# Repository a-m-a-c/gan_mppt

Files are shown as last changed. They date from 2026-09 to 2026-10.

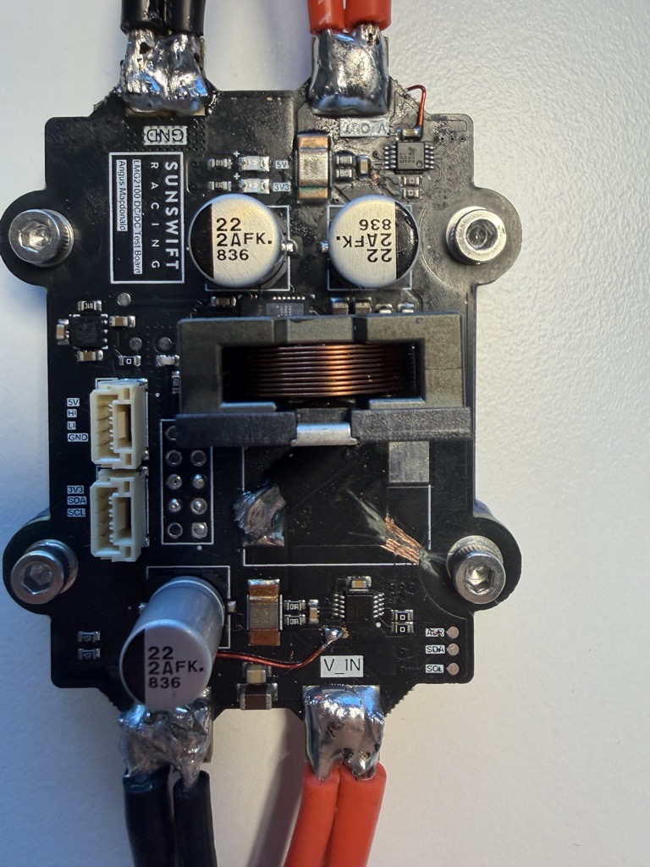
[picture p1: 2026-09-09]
docs/photos/test_board_emi_fix.jpg

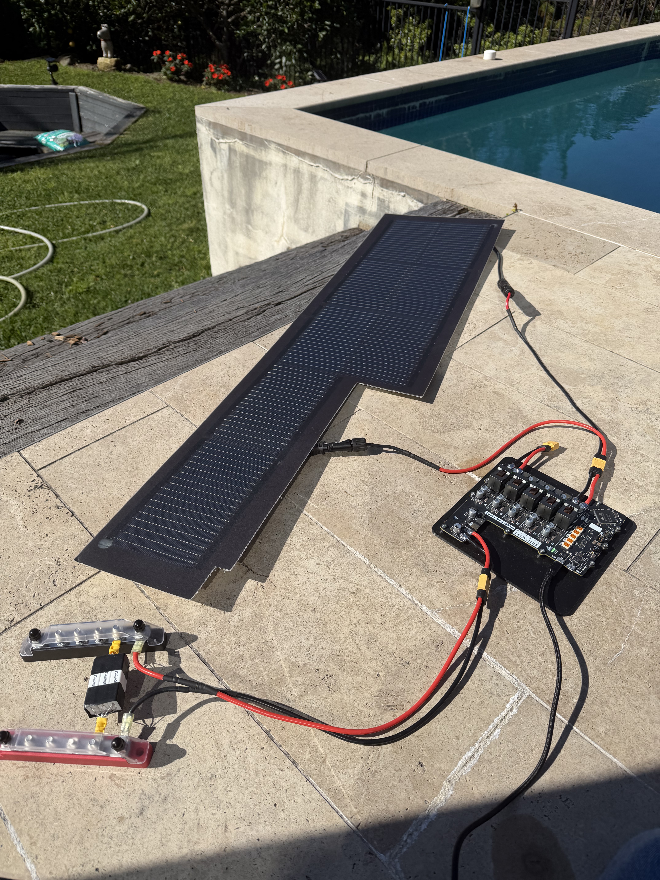
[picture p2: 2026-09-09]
docs/photos/mppt_test_with_pv.jpg

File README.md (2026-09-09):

# gan_mppt

Firmware, hardware designs, and host tools for the five-channel GaN MPPT controller.

```powershell
git clone https://github.com/a-m-a-c/gan_mppt.git
cd gan_mppt
```

| Folder | Contents |
| --- | --- |
| `firmware/` | STM32 firmware, CubeMX project, and CMake build files |
| `hardware/` | Altium schematics, PCB, output job, and schematic PDFs |
| `tools/` | Python bench GUI, serial console, capture and plotting tools; managed by uv |
| `docs/` | Project documents and plots |

Open the repository root in VS Code. Its CMake, flash, and debug settings target
`firmware/`. The firmware's CubeMX project and executable remain named
`gan_mppt_firmware`.

To compile with STM32CubeCLT's CMake, Ninja, and ARM GCC on PATH:

```powershell
cd firmware
cmake --preset Debug
cmake --build --preset Debug
```

To run the host GUI from the repository root with [uv](https://docs.astral.sh/uv/):

```powershell
uv sync --project tools --locked
uv run --project tools --locked python tools/gui/server.py
```

See [tools/README.md](tools/README.md) for the other commands. A serial connection
is selected in the GUI; opening it alone does not connect to the board.

Open `hardware/SR8_MPPT.PrjPcb` in Altium Designer. Local Altium history,
previews, logs, and generated outputs are ignored by Git.

The repository retains the original firmware Git history. Hardware was copied
from the existing Altium project without importing its Git history.

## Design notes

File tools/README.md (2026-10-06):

# GaN MPPT tools

Python 3.11 or newer and [uv](https://docs.astral.sh/uv/) are required.
Dependencies are declared in `pyproject.toml` and resolved in `uv.lock`.

Run from the repository root:

```powershell
uv sync --project tools --locked
uv run --project tools --locked python tools/gui/server.py
uv run --project tools --locked python tools/console.py --list
uv run --project tools --locked python tools/plotter.py --list
uv run --project tools --locked python tools/iv_curve.py <csv>
```

The GUI prints its local URL. Select a serial port and connect when the board
is ready. Captures are saved under the repository's ignored `captures/` folder.

Use the channel toggles above the V-I plane to overlay multiple channels.
Each channel has its own colour, trail and best-power marker. The V-I plane
and time-series plots have separate Pause buttons. Pausing freezes the view
for inspection while live values and captures continue; Resume returns to
the current live data.

To replay an existing capture without connecting to hardware:

```powershell
uv run --project tools --locked python tools/gui/server.py --replay <csv> --speed 4
```

The scripts retain their inline dependency metadata for standalone use.
Use the explicit `python` commands above to run with the project's locked
dependencies. Add shared dependencies with `uv add --project tools <package>`.

`gen_ntc_table.py` writes to `firmware/Inc/drivers/ntc_table.h` and requires
`.agents/NCU18XH103F6SRB.csv`, which is not currently included in the repository.

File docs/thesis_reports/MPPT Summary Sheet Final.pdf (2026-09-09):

Angus Macdonald - z5416730 | Supervisor - Prof. John Fletcher | Assessor - Dr. Pablo Poblete Durruty

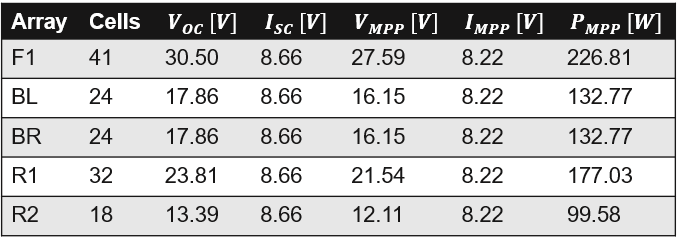
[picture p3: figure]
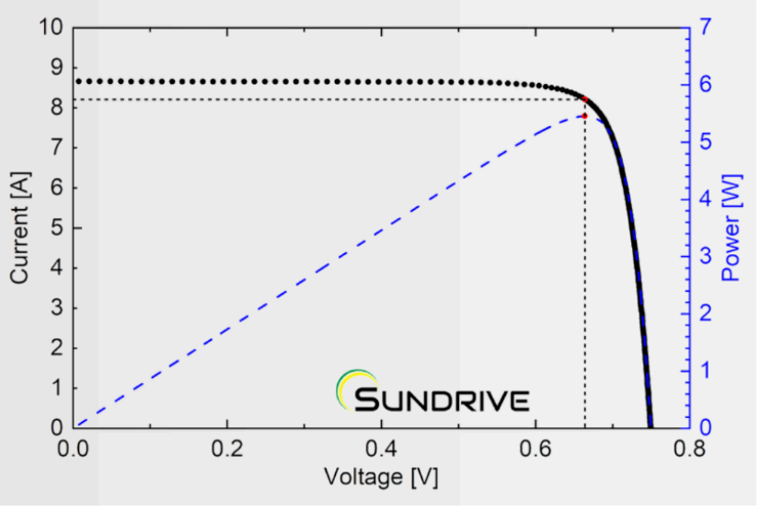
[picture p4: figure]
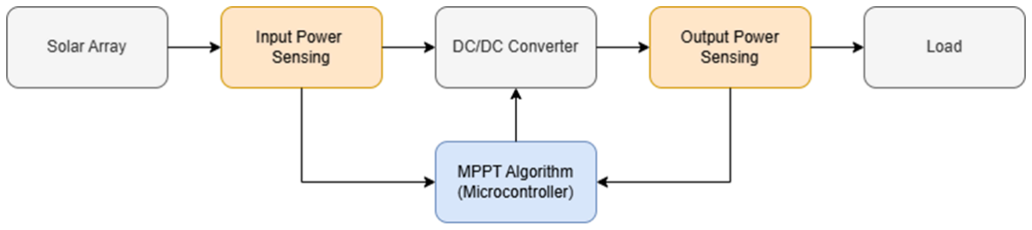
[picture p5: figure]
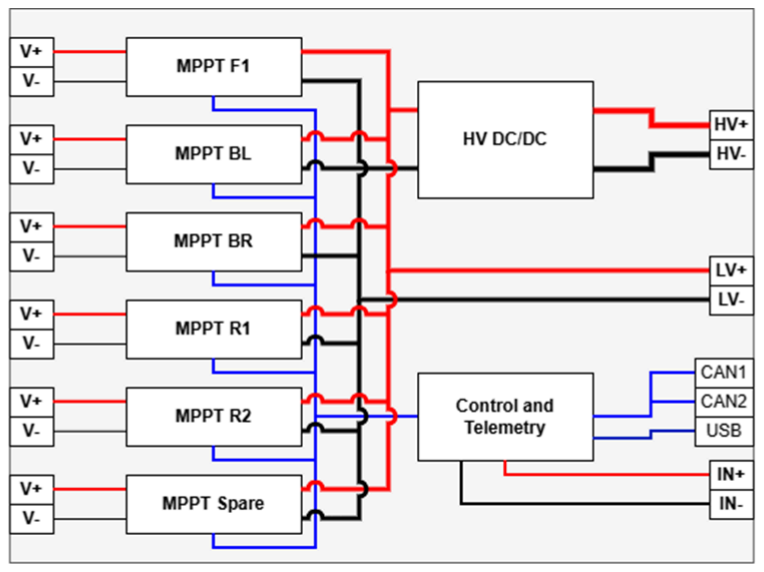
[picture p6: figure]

Maximises energy extraction under dynamic operating conditions while maintaining reliability within strict system constraints.

# Multi-Channel Solar Car MPPT

## Thesis Aim

## General Background

## Proposed System

SR8 - Sunswift 8
ADR - Australian Design Rules LV - Low Voltage
HV - High Voltage

SC - Short Circuit
OC - Open Circuit
MPPT - Maximum Power Point Tracker MPP - Maximum Power Point

PWM - Pulse Width Modulation CAN - Controller Area Network COTS - Commercial Off-The-Shelf GaN - Gallium Nitride

## SR8 System Context & Requirements

This thesis presents a multi-channel MPPT system for Sunswift 8, designed to maximise energy extraction under dynamic conditions.

The system delivers power to both LV and HV buses depending on state-ofcharge, and acts as a flexible platform for MPPT algorithm development and validation.

5 solar arrays (~769 W) feeding LV (~48V) and HV (~690V) bus. Highly dynamic operating conditions duringdriving.
Strict size, protection, & environmental constraints. Energy-limited system, efficiency is critical for range goals.

IV/PV Curve for SR8 Cells

Solar arrays exhibit non-linear I-V characteristics with a maximum power point (MPP).
MPP varies with irradiance, temperature, and partial shading. Complex control algorithms required for dynamic MPP tracking. DC/DC converters enable control of array operating point.

6 independent synchronous boost MPPT channels. Per-array tracking to minimise partial shading losses. Dual-output architecture supporting LV and HV buses. Automatic HV charging transition when LV is at capacity. STM32-based control with high-resolution PWM. Web-based UI for experimental algorithm deployment, telemetry monitoring, and array validation.
Support for FD-CAN and serial communication. Designed for high reliability and seamless integration.

# Thesis A Seminar Summary

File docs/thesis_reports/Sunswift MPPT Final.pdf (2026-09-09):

# Multi-Channel Solar Car MPPT

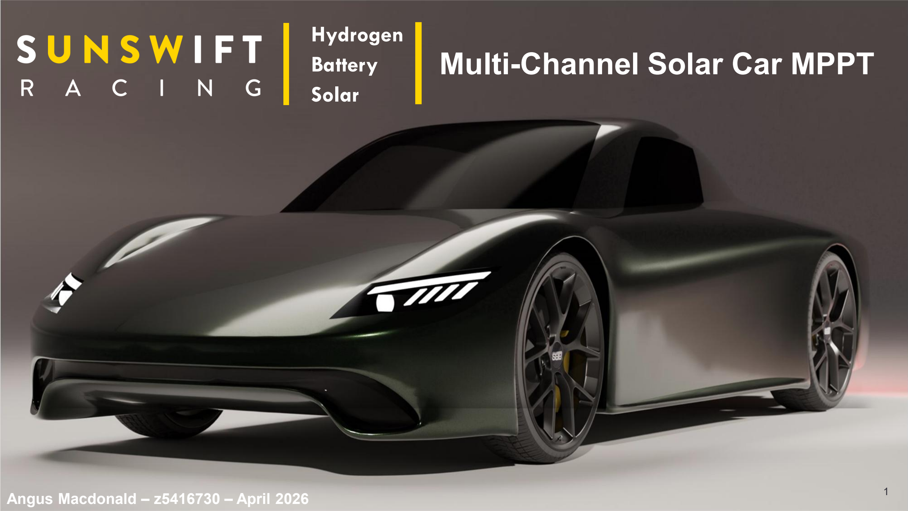
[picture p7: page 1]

### Hydrogen Battery Solar

1
Angus Macdonald – z5416730 – April 2026

# Introducing Sunswift 8

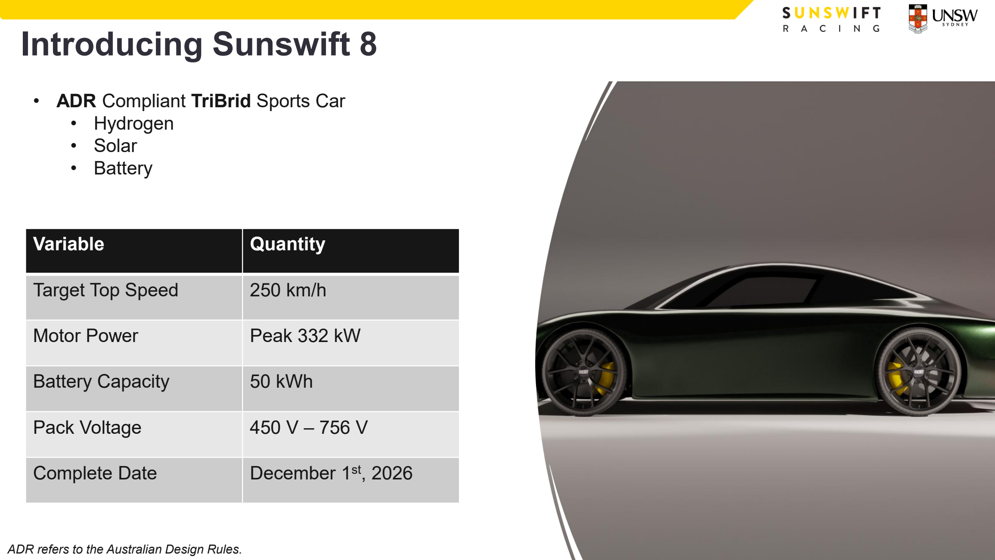
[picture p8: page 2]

2

- ADR Compliant TriBrid Sports Car
- Hydrogen
- Solar
- Battery
Variable | Quantity
Target Top Speed | 250 km/h
Motor Power | Peak 332 kW
Battery Capacity | 50 kWh
Pack Voltage | 450 V – 756 V
Complete Date | December 1st, 2026

ADR refers to the Australian Design Rules.

# Sunswift 8 Electrical Overview

3

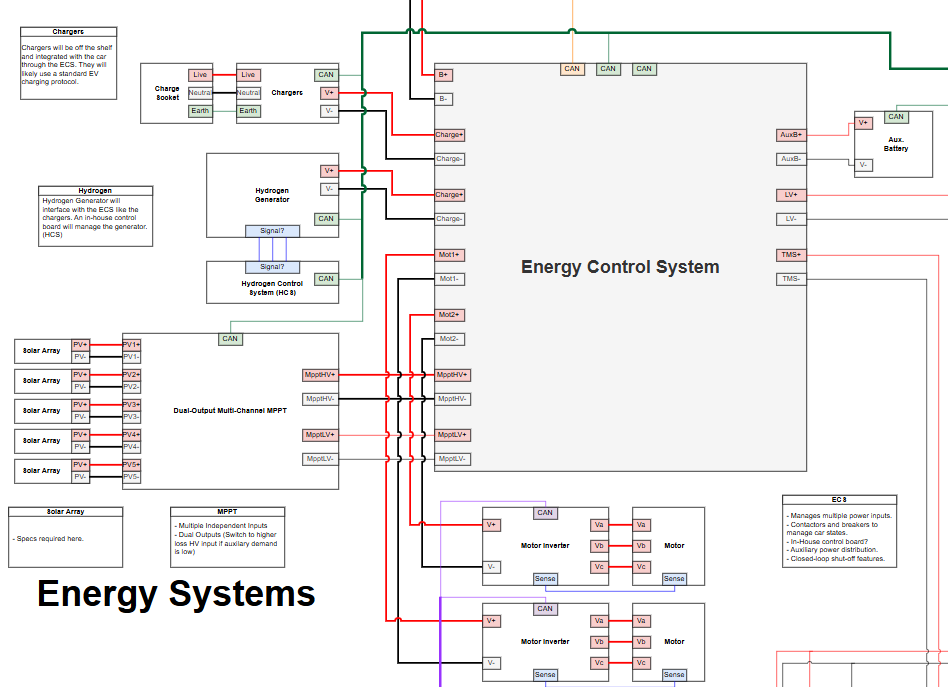
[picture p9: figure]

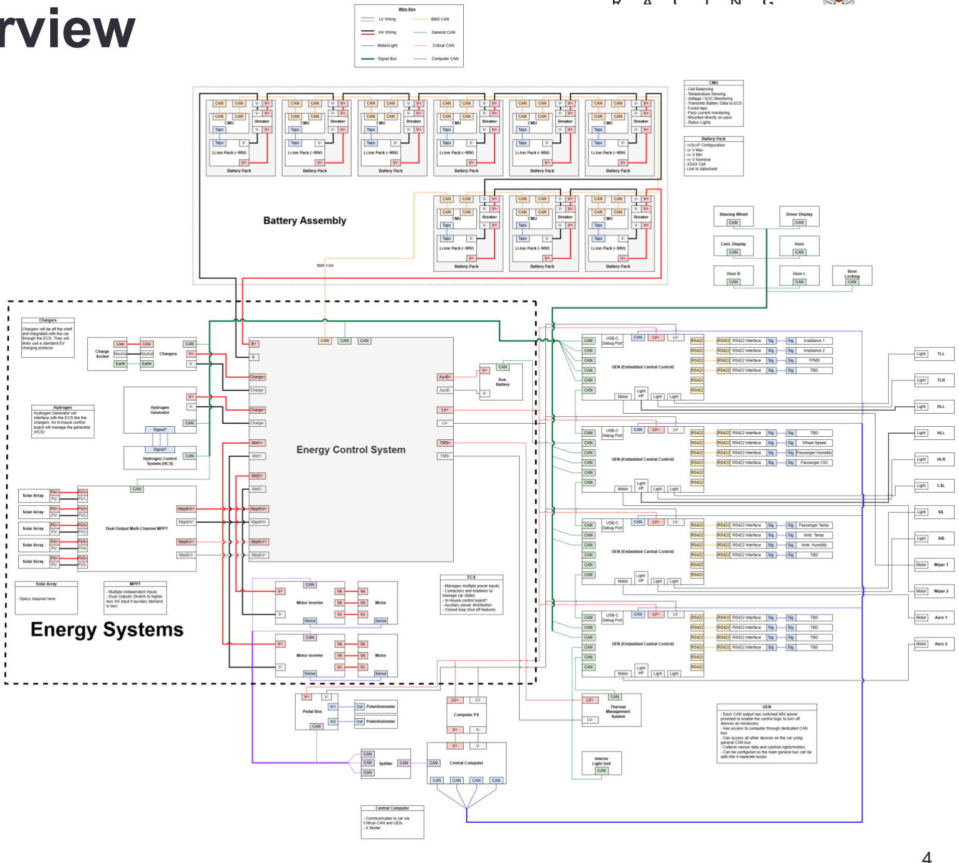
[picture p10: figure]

# Sunswift 8 Electrical Overview

4

- High

-level electrical diagram of SR8
- Battery • Energy Systems • Embedded network
- Two primary electrical bus’s • LV Bus • 13S Molicel INR-21700

-P45B
- 32.5 V minimum • 46.8 V nominal • 54.6 V maximum
- HV Bus • 180S Molicel INR -21700

-P50B
- 450 V minimum • 690 V nominal • 756 V maximum
- Two onboard power generation systems • Hydrogen Fuel Cell • Solar Array

LV indicates low voltage (<100V). HV indicates high voltage (>100V).

# Sunswift 8 Electrical Overview - Solar

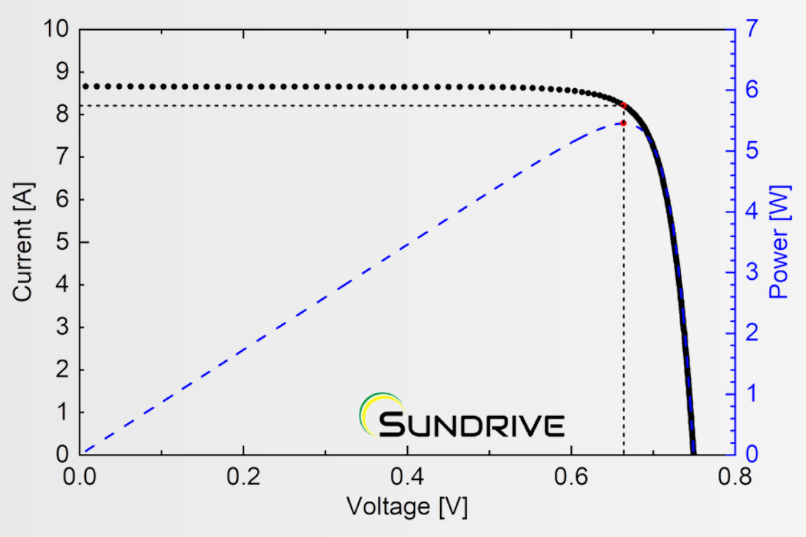
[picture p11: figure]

5

Array | Cells | VOC [V] | ISC [V] | VMPP [V] | IMPP [V] | PMPP [W]
F1 | 41 | 30.50 | 8.66 | 27.59 | 8.22 | 226.81
BL | 24 | 17.86 | 8.66 | 16.15 | 8.22 | 132.77
BR | 24 | 17.86 | 8.66 | 16.15 | 8.22 | 132.77
R1 | 32 | 23.81 | 8.66 | 21.54 | 8.22 | 177.03
R2 | 18 | 13.39 | 8.66 | 12.11 | 8.22 | 99.58

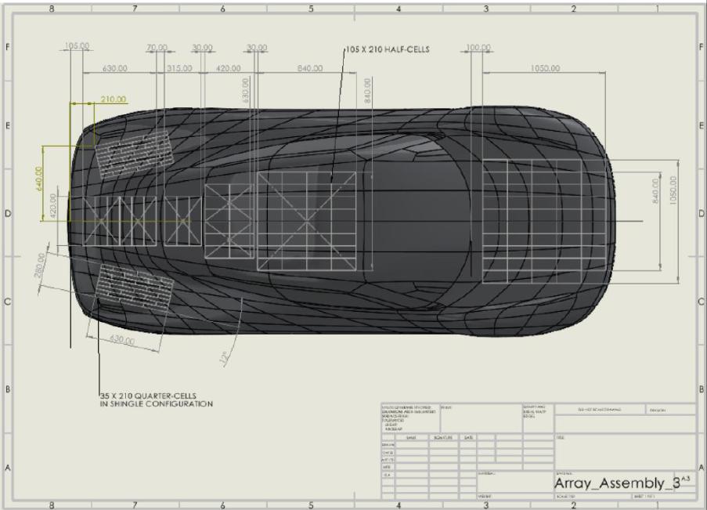
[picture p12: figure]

- SunDrive G12 – 210 SD-HJT Cells
- 25.1% efficient
- 19.35% power loss at 100 °C
- 4.13% current increase at 100 °C
- 5 arrays (all series cells)
- All on different planes.
- Different cell numbers.
- Total power of 769 W.

Values calculated at STC conditions (25 °C, 1000 W
m²

, AM1.5 Spectrum)

F, B, and R indicate front, back, and roof, respectively.

# Maximum Power Point Tracker – IV and PV Curves

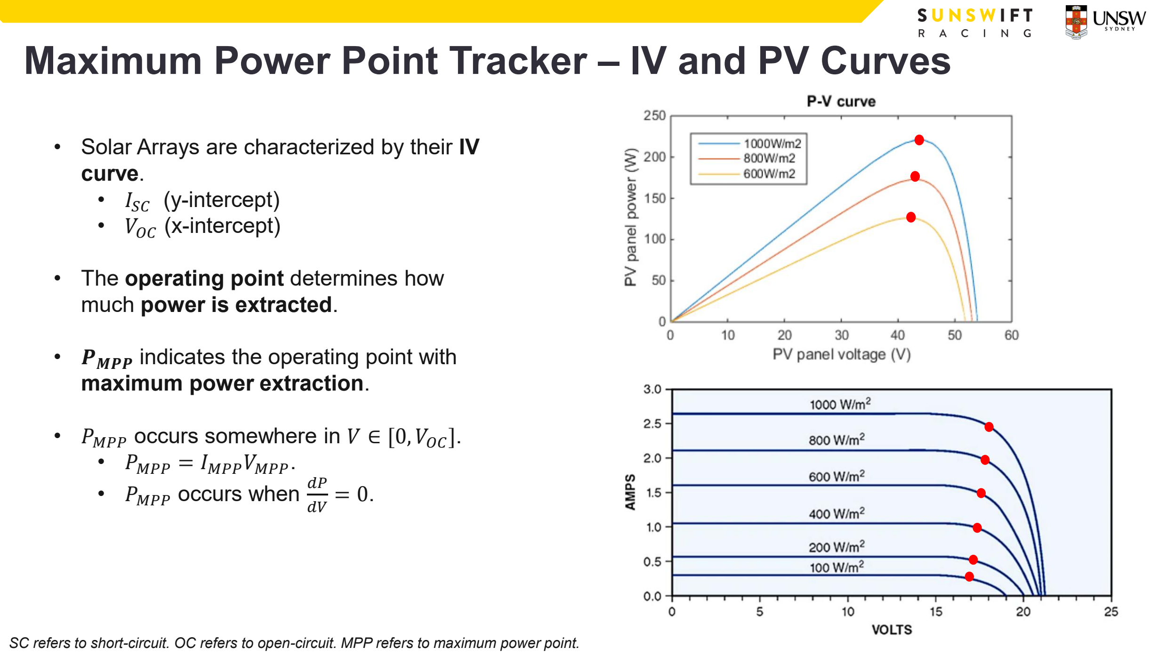
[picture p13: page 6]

- Solar Arrays are characterized by their IV curve.
- ISC (y-intercept)
- VOC (x-intercept)
- The operating point determines how much power is extracted.
- PMPP indicates the operating point with maximum power extraction.
- PMPP occurs somewhere in V ∈ [0, VOC].
- PMPP = IMPPVMPP.
- PMPP occurs when dP
dV

= 0.

SC refers to short-circuit. OC refers to open-circuit. MPP refers to maximum power point.

# Maximum Power Point Tracker – Purpose

- The goal is to operate the panel at PMPP.
- Not doing this results in underutilization of solar resources.
- To operate at PMPP, it must first be found.
- PV curves can have multiple maxima.
- PMPP is dynamic. It requires active tracking.
- Environmental variables are constantly altering the IV curve.

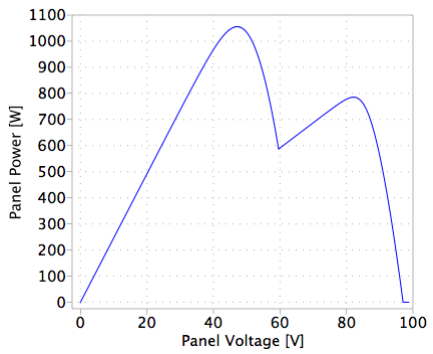
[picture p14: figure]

- PMPP changes rapidly due to dynamic vehicle conditions.
- Irradiance angle shifts as car turns.
- Shading as car travels beneath an object.
Variable | Effect
Irradiance [G] | G ↑, PMPP↑
Temperature [T] | T ↑, PMPP↓
Cell Age [t] | t ↑, PMPP↓
Irradiance Angle [θ] | θ ↑, PMPP↓, [Geff = Gcos θ]
Spectrum Shape | Shifts PMPP
Partial Shading | Multiple PMPP maxima

# Maximum Power Point Tracker – Algorithm

- Algorithms involve measuring input current
and/or voltage.
- Algorithm choice heavily impacts average power.
- Each algorithm has pros/cons.
- Flexibility is key for efficiency.
- My thesis is dedicated to making a platform that can run almost any MPPT algorithm.
- It is important that we have the necessary hardware support.
- More complex algorithms include:
- Particle Swarm Optimization (PSO)
- Genetic Algorithms (GA)
Algorithm | Approach
Perturb and Observe | Perturbs Varr and observes Parr.
Incremental Conductance | PMPP occurs when dI I = − . dV V
Current Sweep | Sweeps operating point to estimate global MPP.
Temperature Method | Estimates VMPP using array temperature.

Common MPPT Algorithms

# Maximum Power Point Tracker – Hardware

## Auxiliary Components

- Input Power Sensing
- To determine solar array operating point.
- Output Power Sensing
- Ensures load is receiving correct voltage.
- Microcontroller
- Allows feedback from power sensors.
- Varies DC/DC duty cycle to load solar array at VMPP.

## DC/DC Converter

- Converts solar array DC power to a useful output voltage.
- DC/DC topology depends on system requirements.
- Input and output voltage.
- Isolation requirements.
- Some examples are:
- Boost, Buck-Boost, Buck (Non-Isolated)
- Flyback, Forward (Isolated)

# Boost Converter Basics

Design Consideration | System Impact | Design Choice (SR8 Context)
Switching Frequency | Switching losses, inductor size/ripple current, capacitance/ripple voltage. | 500 kHz to reduce inductance and maintain low ∆I.
Ripple Current | Minimum Iin before discontinuous conduction mode (DCM). Iin measurement accuracy. | ∆I ≈ 10% ∙ Iin, since high fsw. Allows for ~30μH inductor.
Ripple Voltage | Output stability. | ∆V ≈ 2% ∙ Vout.
Deadtime | Body diode loss. | t = 5ns, based on chosen FET datasheet recommendations.
Sync/Async | Simplicity vs efficiency. | Synchronous
Field Effect Transistor (FET) Technology | Switching frequency, conducted loss, gate drive complexity. | GaN for low RDS(on) and low gate charge.

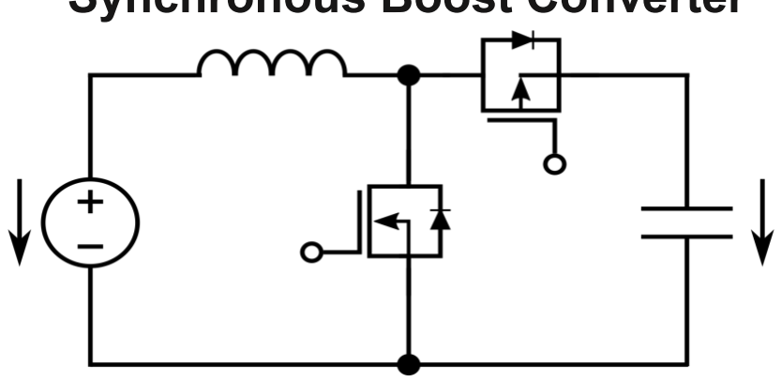
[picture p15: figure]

Key Equations

Vout =

Vin
1 − D

L =

Vin ∙ D
∆I ∙ fsw

C =

Iout(1 − D)
∆V ∙ fsw

fsw =

1

ton + toff

D: Duty Cycle
ton: FET on-time
toff: FET off-time
∆V: Ripple Voltage
∆I: Ripple Current
fsw: Switching Freq.
Key | Synchronous Boost Converter

# Proposed MPPT System Architecture

System Overview
- 6 independent MPPT channels.
- Boost Topology
- Maximizes power in mismatched conditions (shading, relative angle).
- Optional spare input for V1 Hydrogen Fuel Cell (250W)

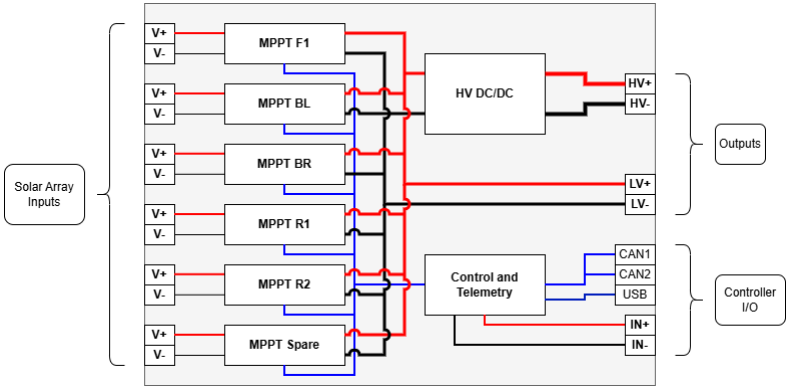
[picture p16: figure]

- Dual outputs for LV and HV bus
- Automatically transitions to HV charging when LV battery is at capacity.
- Centralized control architecture using a STM32H743 with high-resolution PWM.
- Telemetry and control over FD CAN and serial.
- IP67 Enclosure for harsh operating environment.

Design Priorities
- High-reliability operation in a dynamic automotive environment.
- Supports a wide variety of MPPT algorithms.
- Designed as a test and validation platform for solar arrays and MPPT algorithms.

# Solution Comparison Multi-Channel Solar Car MPPT

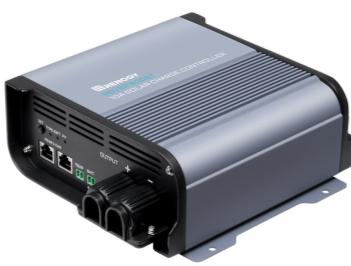
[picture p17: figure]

Renogy Rover Boost 10A

System | Pros | Cons
COTS SMPPT | • Readily available • Very high efficiency | • Require 5 due to prevent array bottlenecks • Heavy > 1 kg • Large > (20 x 10 x 10 cm) • Limited CAN integration • No algorithm control
DC Optimizers | • Per-string MPPT (reduces mismatch losses) • Proven commercial solution. | • Limited telemetry. • Not intended for automotive use. • No algorithm control. • Integration complexity (discrete modules)
My Solution | • Centralized DC Optimizer • Handles LV and HV charging • Algorithm flexibility • Rich CAN telemetry | • Design complexity. • Boutique solutions are often more expensive.

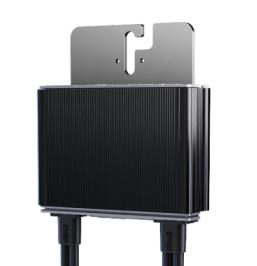
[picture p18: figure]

SolarEdge DC Optimizer

# Supporting Research

Investigation of single and multiple MPPT structures of solar PV-system under partial shading conditions considering direct duty-cycle controller

# Multi-Channel Solar Car MPPT

SMPPT refers to a single maximum power point tracker. PV refers to photovoltaic modules.

“Partial shading of solar panels diminishes their operating efficiency and energy synthesized as it disrupts the uniform absorption of sunlight”

Abdel-Raheem Youssef, Mostage M. Hefny, Ahmed Ismail M.Ali (Scientific Reports 13, Article number: 19051) (2023)

Key Takeaways

- Directly supports current approach.
- Small shading significantly reduces overall PV system efficiency.
- SMPPT systems are bottlenecked by weakest performing cell.
- Faster dynamic response.

“An SMPPT can only track the MPP of a single PV module or string at a time”

“Even a small shading area… causes the entire system to operate at a sub-optimal MPP.”

# Supporting Research

Performance analysis of solar PV based DC optimizer distributed system with simplified MPPT method (Springer, 2020)

Theoretical and behavioral analysis of power optimizers for grid-connected PV systems
(Elsevier, 2022)

A Comprehensive Review of
Distributed MPPT for Grid-Tied PV Systems at the Sub-Module Level (Alharbi, Darwish, Ma, 2023)

# Multi-Channel Solar Car MPPT

DC optimizers enable individual MPPT per panel and eliminate mismatch losses.

Power (DC) optimizers are a distinct PV architecture designed to handle shading, mismatch, and non-uniform conditions.

Distributed MPPT systems give better efficiency and under shading. better performance

DC Optimizer Literature | Key Takeaways

# Design Challenges

Hardware

- HVDC PCB Design (~750V).
- Creepage, clearance, insulation.
- High-efficiency, high-frequency DC/DC design.
- Layout sensitivity due to fast GaN switching.
- Mechanical integration.
- Thermal management.
- Compact and waterproof.
- Robust protection and fault handling.
- Battery protection
- Pre-charge, overcurrent, etc.

# Multi-Channel Solar Car MPPT

Firmware

- Real-time control across multiple power stages.
- Software defined protection logic.
- Modular algorithm framework.
- FD CAN and serial telemetry.
- User interface for testing and deploying algorithms.

Testing & Validation

- Testing under dynamic real-world solar car conditions.
- Protection systems validation.
- Testing a HV system.
- Dangerous and requires
appropriate training.
- Vehicle integration.

# Project Plan

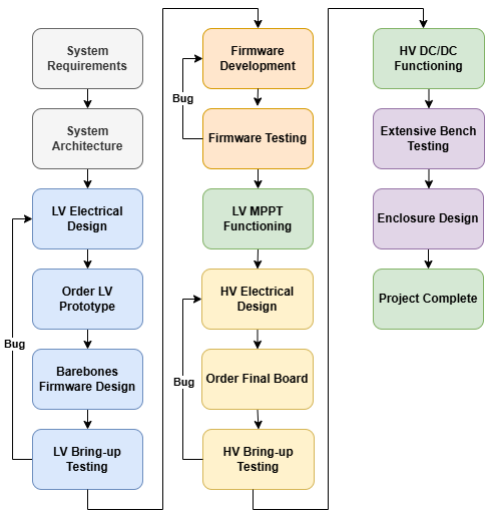
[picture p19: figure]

System Requirements and Architecture

LV Design and Test

Firmware Design and Test

HV Design and Test

Performance Evaluation and Integration

2

1

3

4

5

Project Stages

MVP – Achieve functioning 5-channel LV MPPT with >90% efficiency between 0-8.2 A (input).

External HV DC/DC can be procured for HV solar charging.

# Project Timeline

February | March | April | May | June | July | August | September | October | November
System Requirements and Architecture LV Design and Test
Firmware Design and Test
HV Design and Test
Performance Evaluation and Integration Documentation and Report Writing
Project Timeline | Term 1 | Term 2 | Term 3

# Required Skills and Training

Skill | Application | Proficiency
Altium Layout and Schematics | Electrical hardware development. | Strong – Designed PCBs for Sunswift and industry.
HV Design and Handling | HV DC/DC development. | Developing
Power Stage Design | Boost converter design. | Strong – Developed synchronous buck converters.
Firmware Design in C | Control and algorithm execution. | Developing
SolidWorks | Enclosure design. | Strong – Developed and printed test jigs.

# Preliminary Results and Progress

Key Component Selection

- Microcontroller
- STM32H743ZIT6
- LV GaN FET
- LMG2100R026
- Integrated gate driver.
- Python scripts for minimum
inductance and capacitance.
Solar Array | Inductance [μH] | Capacitance [μF]
F1 | 31.9 | 18.4
BL | 26.6 | 6.3
BR | 26.6 | 6.3
R1 | 30.5 | 3.5
R2 | 22.0 | 3.2

LMG2100R044 Testing

- Development board in boost configuration.
- 22μH inductor.
- ~7μF capacitance.
- Preliminary testing showed ~96% efficiency at F1 voltages.
- Further testing is required; measurement inaccuracies could be up to ±2%.
- Results gave me the confidence to select this FET and gate driver package.

# Preliminary Results and Progress

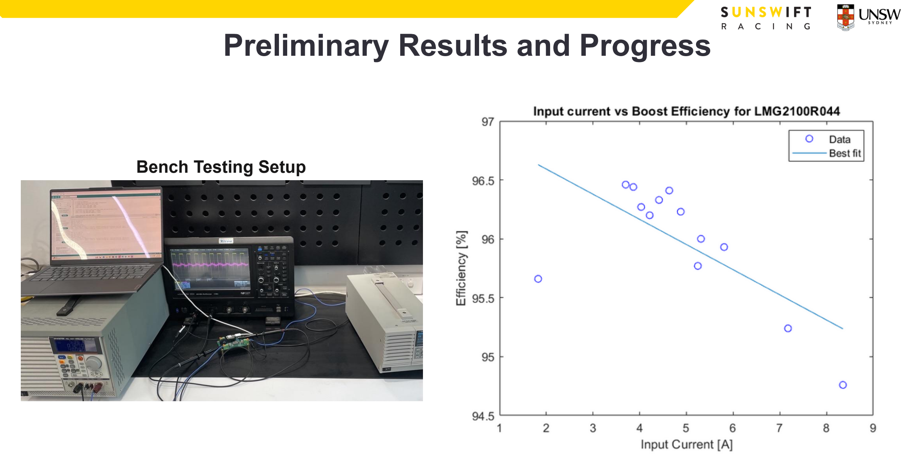
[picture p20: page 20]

Bench Testing Setup

# Questions?

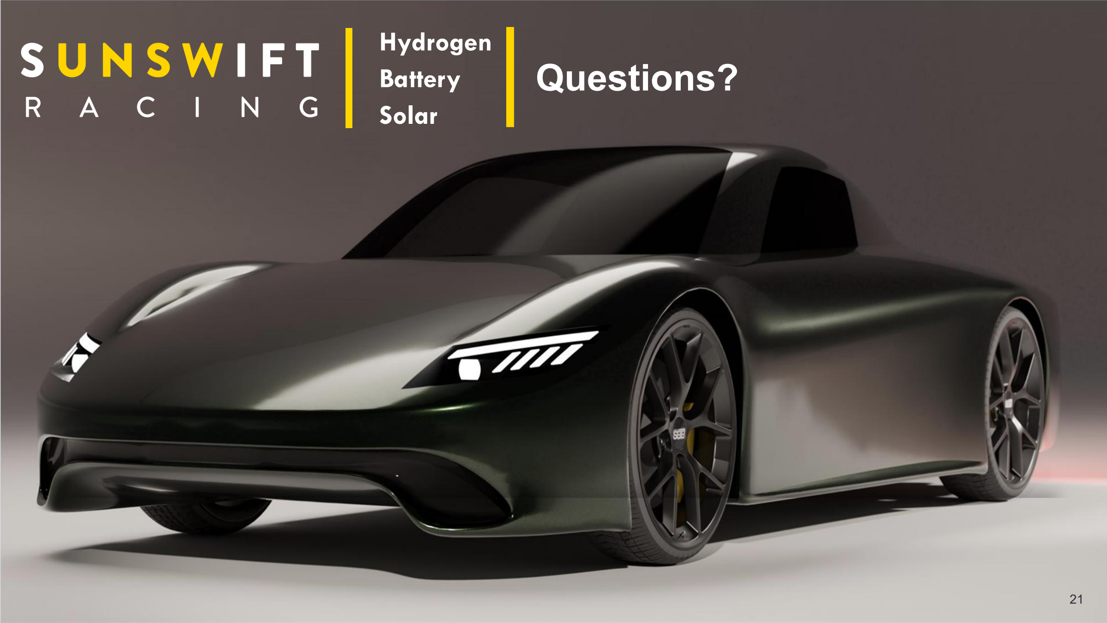
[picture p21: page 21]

### Hydrogen Battery Solar

21

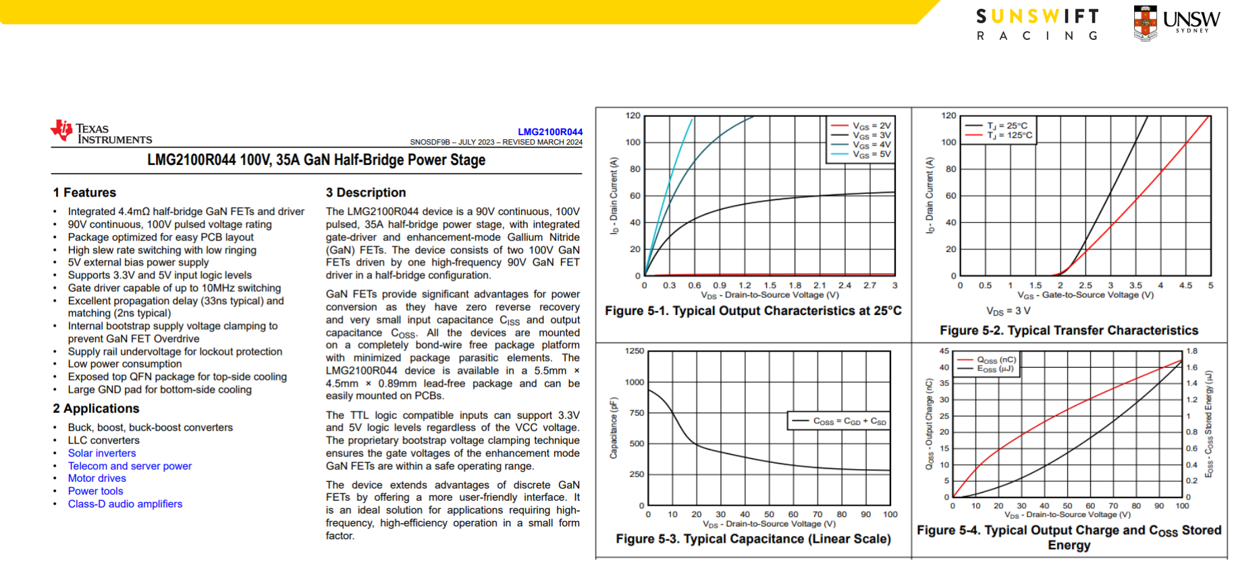
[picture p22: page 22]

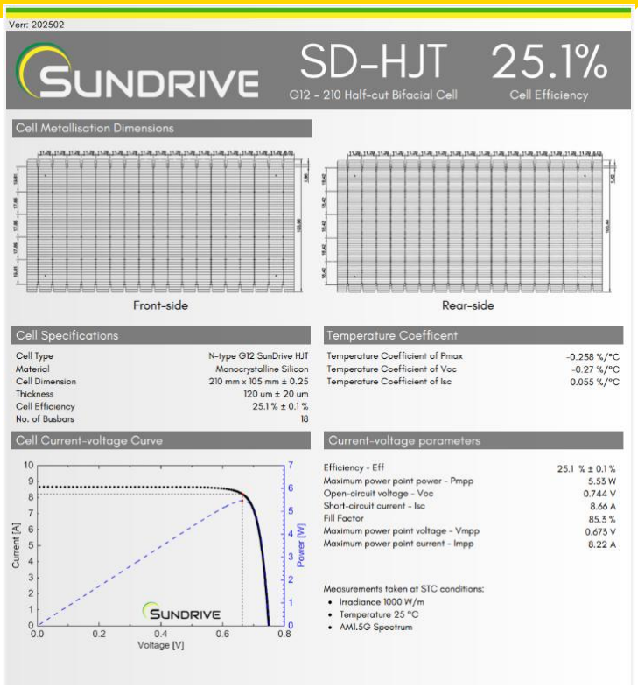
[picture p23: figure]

# Why this architecture?

Solar Car Challenges

- Frequent partial shading.
- Rapid PMPP changes due to dynamic conditions.
- Tight space requirements.
- Environmental constraints.
- Vibration.
- Waterproofing.

# Multi-Channel Solar Car MPPT

COTS Limitations

- Significantly larger when implementing equivalent
functionality using COTS products.
- No control over MPPT algorithm implementation.
- No dual output support at our required voltages.

COTS refers to Commercial Off-The-Shelf products.

Enables maximum energy extraction under all operating conditions while maintaining reliability and flexibility with tight system constraints.

Solution Advantages

- Optimal per-array tracking.
- Dual LV/HV output in single package.
- Compact design enabling
simplified SR8 integration.
- Flexible platform for algorithm development and array validation.

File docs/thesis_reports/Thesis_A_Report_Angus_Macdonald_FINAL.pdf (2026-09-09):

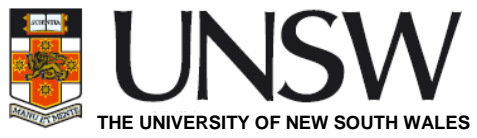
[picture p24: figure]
THE UNIVERSITY OF NEW SOUTH WALES

School of Electrical Engineering and Telecommunications

# ELEC9451 / ELEC4951

### THESIS/PROJECT PART A TECHNICAL REPORT COVER-SHEET

Study the marking guide and the requirements given overleaf. Complete the details required on this form and include it at the front of your report (first page).

Student name: _________________________________ Student ID: ___________________

Thesis/Project title: __________________________________________________________

Supervisor: __________________________ Assessor: _____________________________

I declare that this assessment item is my own work, except where acknowledged, and has never been submitted for academic credit elsewhere, and acknowledge that the assessor of this item may, for the purpose of assessing this item,
(i) reproduce this assessment item and provide a copy to another member of the University, and/or
(ii) communicate a copy of this assessment item to a plagiarism checking service (which may then retain a copy of the assessment item on its database for the purpose of future plagiarism checking).

I certify that I have read and understood the University Rules about Student Academic Misconduct.

Signature: | Date:
Angus Macdonald | z5416730

Design of a Multi-Channel MPPT System for Solar Vehicle Applications

Prof. John Fletcher | Dr. Pablo Poblete Durruty

23/4/2026

Marking scheme

Reviewing work of others: Problem statement; hypothesis and aims; literature review (comprehensive, up-to-date, critical assessment of existing work). | Weighting 50%
Project planning and partial execution: Articulating research question; ability to apply logical thinking in gathering information, analyzing available information, formulating plans, proposing solutions; thesis outline; preliminary work already completed like simulations, solving simpler sub-problems or becoming skilled in the use of relevant tools | 40%
Document presentation: Physical presentation (report structure, legibility, layout); quality of writing (grammar, spelling, wording, style, clarity, adequately proofread); referencing (fully documented reference list, using correct citation conventions); report self-contained, (provide all information needed) | 10%

Overall directives and checklist

1. You must not commit plagiarism. Any report considered to contain plagiarism will be passed to the Head of School for further action. (see https://student.unsw.edu.au/plagiarism)
2. Late submission of this report will be penalised
3. If your report is unsatisfactory (i.e. not suitable for a professional engineer), then you may be required to resubmit an amended version. A report can be judged unsatisfactory for ANY of these reasons
a. use of units not conforming to SI standards;
b. use of discriminatory or non-inclusive language;
c. failure to follow correct referencing conventions;
d. a consistently inappropriate style (e.g. as though written for school-children, a sales brochure, or a tabloid newspaper, rather than for professional engineer to read);
e. failure to have an appropriate structure (abstract, introduction, conclusion, etc); or unreadable text, symbols or figures.

The following checklist will assist with various aspects of preparing your report. Before submitting, check these issues. They are requirements:

1. The report is submitted as a single pdf file. The cover-sheet, completed and signed by hand, is scanned and included in this report as the first page.
2. The report is written and formatted using a word processing program: A4-paper size, 2.5cm margins, 12 pt font text, spacing of 1.5 lines, consecutively numbered pages.
3. The report is the specified length. I have attempted to make it concise (i.e. "brief but comprehensive in expression" -Concise Oxford Dictionary).
4. The report is intended to be understood by someone less well versed in the topic than the author. It does not verbosely repeat material from the references. It attempts to convey to the more informed reader the extent of the author's understanding of the topic.
5. There is a title-page, which includes the name of the author, title of the report, the course code & name, and the date, following this cover-sheet.
6. The Abstract and Introduction fulfill their purposes, as conventionally understood (i.e. the abstract stands on its own as a summary of the report, whereas the introduction states the issues, places them in context and, perhaps, suggests the general line of argument, the scope of the following sections, and the conclusions).
7. The Conclusion summarises and assesses the arguments, emphasises the more important ones, and mentions unresolved issues.
8. There is an Appendix for the Risk Assessment Form.
9. The sections of the report are numbered and appropriately titled. If they are used, tables, diagrams, etc. are also clearly numbered.
10. There is a Table of Contents following the Abstract and on a page of its own.
11. The references are contemporary, cover the breadth of the topic, and demonstrate my familiarity with its major aspects. References are correctly included in the body of the report.
12. The report has been proof-read and spelling, grammar, & punctuation have been checked.
13. Acronyms & jargon are either avoided or clearly explained.
14. Inclusive and nondiscriminatory language is used throughout.
15. Units and their abbreviations conform to SI standards.

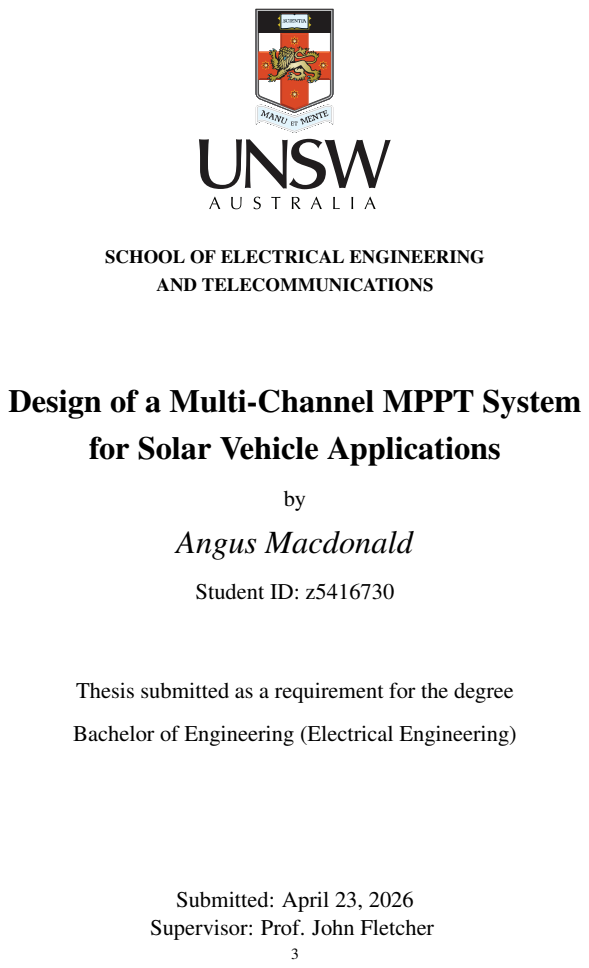
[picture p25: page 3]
AND TELECOMMUNICATIONS; by Angus Macdonald; Student ID: z5416730

SCHOOL OF ELECTRICAL ENGINEERING

Design of a Multi-Channel MPPT System
for Solar Vehicle Applications

Thesis submitted as a requirement for the degree

Bachelor of Engineering (Electrical Engineering)

Submitted: April 23, 2026
Supervisor: Prof. John Fletcher

Abstract

Sunswift Racing is an ambitious student project focused on pushing the boundary of solar

car technology. In the past, their developments have focused on solar race cars for the BWSC

competition. The team has now transitioned to developing their next vehicle, Sunswift 8. This is

a TriBrid ADR compliant vehicle that contains three distinct power sources, battery, hydrogen,

and solar power. Integration of solar arrays into automobiles is a relatively niche market given

the engineering and manufacturing complexity needed to derive useful amounts of energy from

the small usable surface area on a traditional car. Efficient solar extraction for automobiles

comes with a unique set of challenges that differ greatly from conventional solar projects. These

include, but are not limited to; large differences in effective irradiance between arrays, frequent

partial shading, varying temperature gradients, tight space constraints, and harsh automotive

environments. The goal of this thesis is to develop an integrable product for Sunswift 8 that

extracts maximal energy from the onboard photovoltaic arrays and delivers it to the LV and HV

batteries in the car. Traditionally, solar arrays are connected in series or parallel and a single

MPPT is used to extract power. This thesis proposes per-string power-point tracking using

synchronous boost converters, with all MPPT modules integrated on a single board. It will also

act as a robust system to deliver power to the LV bus and incorporate a separate power stage to

allow HV EV battery charging.

# Acknowledgements

I would like to thank my thesis supervisor, Prof. John Fletcher, for supporting me in this

development. His expertise has guided many of my decisions throughout this project. I also

would like to thank the team at Sunswift Racing, in particular the Energy Systems department,

for continuously supporting me and taking their time to provide me with useful feedback.

# Abbreviations

PV Photovoltaic

ADR Australian Design Rules

BWSC Bridgestone World Solar Challenge

TriBrid An automobile with three energy sources

SR8 Sunswift 8

LV Low voltage

HV High voltage

MPP Maximum power point

MPPT Maximum power point tracker

SMPPT Single maximum power point tracker

EV Electric vehicle

SC Short circuit

OC Open circuit

DC Direct current

PWM Pulse width modulation

CAN Controller area network

COTS Commercial Off-The-Shelf

BMS Battery management system

STC Standard test conditions

HJT Heterojunction

# Contents

Acknowledgements | 1
Abbreviations | 2
Contents | 4
List of Figures | 6
List of Tables | 7
1 Introduction | 8
2 Literature Review | 11

3 Proposed Solution | 28
4 Preliminary Work | 34
5 Project Planning | 41
6 Conclusion | 43
Bibliography | 44
Appendix 1 | 46
Appendix 2 | 51

# List of Figures

2.1 PV Curve of Sundrive G12-210 SD-HJT cell[15] | 12
2.2 Asynchronous boost converter | 18
2.3 Synchronous boost converter | 19
2.4 Flyback Converter | 22
2.5 DC optimiser configuration[10] | 27
3.1 Block diagram of solution architecture | 31
4.1 MPPT draft layout | 39
4.2 Input current vs boost efficiency | 40
5.1 Project flowchart | 42
5.2 Project timeline | 42
1 | Power sensor I2C address | 47
2 | Top-level schematic view of channel 1, 2, and 3 | 47
3 | Top-level schematic view of channel 4, 5, and 6 | 48
4 | Top-level schematic view of MCU and MCU support blocks | 48
5 | FD-CAN isolated transceiver circuit | 49
6 | LV MPPT boost converter schematic | 49
7 | SER2211 series inductor curves | 50

# List of Tables

3.1 SR8 battery specifications | 28
3.2 Sundrive G12-210 SD-HJT cell characteristics [15] | 29
3.3 SR8 PV array characteristics | 30

# Chapter 1

# Introduction

Photovoltaic (PV) technology is a widely adopted method of electrical power generation due to

its ability to convert light into electrical energy[8]. This has enabled integration across a broad

range of industries, including aerospace, grid-scale power generation, and embedded systems.

However, the integration of PV arrays into automotive platforms introduces a distinct set of

engineering constraints that are not present in conventional PV systems[3]. Limited surface

area, non-uniform irradiance, and dynamic operating conditions lead to significant mismatch

losses in PV systems[12]. As a result, effective utilisation of PV technology in automotive

applications requires specialised system design to address these challenges[1].

## 1.1 Background

PV cells exhibit a non-linear IV characteristic, meaning that a maximum power point tracker

(MPPT) must be used to extract power at the correct operating point for maximum efficiency.

The IV characteristic curve of a PV cell is impacted by environmental factors which change

the maximum power point (MPP), so the control algorithm must allow the MPPT to constantly

track and recognise this MPP. The temperature, irradiance spectrum shape, partial shading, ef-

fective irradiance angle, cell age, and irradiance level all shift the MPP of the panel non-linearly

as this affects the IMPP and VMPP of an individual cell depending on the environmental factor.

PV arrays are comprised of PV cells, and these cells can be configured in series or parallel.

Often arrays are configured in series strings, and multiple strings may be configured in parallel

to be connected to a single MPPT. A major problem arises with this approach, in the form of mismatch losses. Mismatch losses occur when one cell experiences different environmental

factors to other cells in a string. This causes the IMPP of this cell to become smaller then other

cells in the string, limiting the other cells of the string to the IMPP of the weakest cell, creating

major efficiency losses.

There are many ways to configure PV arrays and MPPT placement to optimise PV technol-

ogy for a specific use case, and to help negate mismatch losses that lower the efficiency of

PV arrays. The pronounced mismatch losses in automotive systems renders SMPPT solutions

impractical for efficient operation.

## 1.2 Problem Statement

Environmental factors are present in any PV system, and precautions must be taken to ensure

that PV strings do not become affected by mismatch losses. The most prominent causes of mis-

match losses are due to effective irradiance angles and partial shading. In conventional solar

projects, solar panels are designed to be flat to minimise differences in irradiance angle, and

solar panels are placed such that partial shading affects do not occur. For example, a solar farm

is placed in a wide open area with no trees or obstructions to cause shading, and the irradiance

angle is consistent in each panel due to the flat panel design.

In the design of SR8, these luxuries could not be afforded. PV arrays could only be placed

on the curved aerodynamic body panels, and these arrays cannot be placed on the same plane.

This means that the arrays cannot be connected in series with a SMPPT, otherwise major mis-

match losses will occur.

An automotive environment also exhibits highly dynamic operating conditions dissimilar to

any other PV system environment creating large mismatch losses. This means that a more

complex MPPT system is required to efficiently extract usable amounts of power from PV ar-

rays on a vehicle. Given the pronounced mismatch effects due to panel angle and environmental

conditions , a multi-channel MPPT architecture is required.

## 1.3 Thesis Objectives

This thesis is focused on the design of a MPPT module for automobiles with integrated PV ar-

rays that allows for maximal efficiency in the highly dynamic environmental conditions that ef-

fect PV arrays on vehicles. This MPPT module will be developed in conjunction with Sunswift

Racing, with design decisions focused on optimising the power extraction from SR8’s onboard

PV arrays.

The ultimate objective is to deliver Sunswift Racing a robust integrable product that requires

very little configuration to receive optimal performance. This product will acknowledge the

unique operating conditions of a PV system in an automotive environment, and take appropri-

ate design measures to limit or negate mismatch losses in this system. This product can be

broken down into four main objectives which are outlined below:

1. Design and validate a per-string MPPT architecture
2. Develop and validate a HV conversion stage capable of interfacing LV MPPT outputs

with the HV EV battery system.

3. Research and integrate existing MPP tracking algorithms into this system. Develop the

firmware required to safely integrate this MPPT system into the SR8 electrical architec-

ture.

4. Integrate LV, HV, and firmware design components into a single product that can be

deployed in the SR8 vehicle.

## 1.4 Chapter Outline

This report is written with 5 main sections. Chapter 2 reviews the background surrounding

MPPT systems and PV systems, along with existing solutions for efficiently extracting power

from PV arrays in automotive systems. Chapter 3 overviews the proposed solution to this prob-

lem in detail. Chapter 4 outlines work undertaken in thesis A to progress the thesis objectives.

Chapter 5 is a summary of the plan to complete the thesis objectives and provide Sunswift

Racing with this product by the end of this year. Chapter 6 summarises the key aspects of this

report.

# Chapter 2

# Literature Review

## 2.1 Photovoltaic Cell Characteristics

Photovoltaic (PV) cells convert the energy in light to electrical power by using the photovoltaic

effect[8]. Photons impact a semiconductor material and displace electrons, creating electron-

hole pairs and inducing a current. This generates a DC voltage across the PV cell. PV cells can

be arranged in series or parallel like a battery, increasing terminal voltage or current, respec-

tively. PV cells exhibit a non-linear IV curve[17]. This is illustrated in figure 2.1.

### 2.1.1 The IV Curve

Understanding the behaviour of a PV IV curve is critical to designing and creating a MPPT.

Electrical components such as resistors have linear IV characteristics, which means that I ∝ V.

The IV characteristic of a PV cell can be described as a ”bent” shape. As the voltage increases

from zero, the current remains unchanged. As you continue to increase the voltage past a cer-

tain threshold, the current will drop to zero. The IV curve can be translated into a PV curve by

calculating P = IV at every point. This clearly describes where the MPP of the PV cell occurs.

All commercial PV cells describe this behaviour with 4 critical parameters.

VOC The open-circuit (OC) voltage occurs at I = 0, when there is no load on the cell.

ISC The short-circuit (SC) current occurs at V = 0, when there is a short across the cell.

VMPP The maximum power point (MPP) voltage is an intrinsic parameter determined by PV

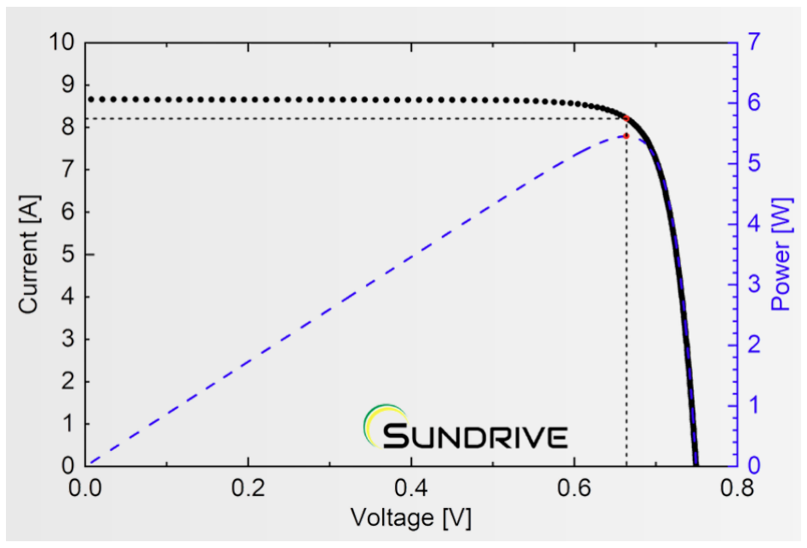
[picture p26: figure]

Figure 2.1: PV Curve of Sundrive G12-210 SD-HJT cell[15]

cell construction. This is the desired operating voltage of the panel for maximal effi-

ciency.

IMPP The maximum power point (MPP) current is an intrinsic parameter determined by PV cell

construction. This is the desired operating current of the panel for maximal efficiency.

Commercial solar cells measure these key parameters under standard test conditions (STC).

These conditions are 1000 W/m

2 of irradiance, 25 ◦C cell temperature, and an AM1.5 air mass

spectrum.

These parameters are not fixed and are highly dynamic based on PV cell inputs and environ-

mental factors. This means that PV cells cannot be loaded simply at the STC MPP operating

point, and the shape and position of the IV and PV curves are constantly changing. This is the

reason PV systems require an MPPT for efficient operation[5].

### 2.1.2 Impact of Irradiance on the IV Curve

The core mechanism that changes the shape of the IV curve is the irradiance (G) received by the

PV cell. Irradiance is an indicator of the energy in light. A higher irradiance indicates a greater

photon flux incident on the cell surface. At a high level, this displaces more electrons in the PV

cell semiconductor material, generating more electron-hole pairs, and therefore increasing the photocurrent in the PV cell. This effect is reflected in the IV curve, as ISC ∝ G[8]. This increases

IMPP approximately linearly and, therefore, PMPP. PV cells also exhibit diode characteristics

that govern the voltage response to changes in irradiance, encapsulated in equation 2.1. When

I = 0, the equation can be rearranged as equation 2.2.

I = Iph −I0

e

V
nVT −1
[17] (2.1)

VOC = nVT ln
Iph
I0

+1

[17] (2.2)

Where Iph is the photocurrent generated by incident irradiance, I0 is the diode saturation cur-

rent, n is the diode ideality factor, and VT is the thermal voltage given by VT =

kT
q

Since Iph is approximately proportional to irradiance, equation 2.2 shows that VOC increases

logarithmically with G[17]. As a result, changes in irradiance produce only a small variation

in voltage compared to the linear increase in current.

The irradiance received by the PV cell surface is dependent on the angle of incidence. Equa-

tion 2.3 shows the effective irradiance received by a cell when the cell is oriented at an angle θ

to the incoming light.

Ge f f = Gcos(θ)[8] | (2.3)

In PV systems like SR8 where cell arrangements are curved or multiple arrays are oriented

differently, the result is a difference in irradiance received by the cells. This means that PV

cells will have different IV curves and MPP operating points. If PV cells are connected in

series, the string current will be constrained by the cell generating the lowest photocurrent,

resulting in a reduced PMPP.

### 2.1.3 Impact of Temperature on the IV Curve

Temperature also affects the shape of the IV curve. PV cell data sheets typically provide tem-

perature coefficients describing the variation of PMPP, VOC, and ISC with temperature. An in-

crease in temperature results in a slight increase in ISC due to enhanced carrier generation[8].

However, the diode saturation current I0 increases exponentially with temperature, while the

thermal voltage VT increases linearly, as seen in equation 2.4[17]. From Equation 2.2, the

exponential increase in I0 dominates, resulting in a significant reduction in VOC[17]. Conse-

quently, the IV curve shifts to lower voltages, leading to a reduction in VMPP and the overall

power output[8].

VT =

kT
/
q[17] | (2.4)

Other factors such as cell degradation, partial shading, and non-uniform irradiance spectrum

also influence the IV curve. In particular, non-uniform conditions across PV arrays introduce

significant deviations in operating behaviour between PV cells. This is examined in detail in

the following section.

## 2.2 Partial Shading and Mismatch Losses

Commercial PV cells are modular by design and are typically interconnected to form appli-

cation specific configurations. PV cells are connected in series to form strings, and multi-

ple strings may be connected in parallel to form an array. In series connected strings, the

same current must flow through all cells, which constrains performance under non-uniform

conditions[7]. When strings are connected in parallel, the terminal voltage of all strings must

be equal[7]. Parallel mismatch is less severe than series mismatch, but can still reduce total

power.

Mismatch occurs when PV cells exhibit different IV characteristics due to variations in irra-

diance, temperature, or orientation[7]. As a result, each cell has distinct VMPP and IMPP values.

Under uniform conditions, cells have similar IV curves and can operate near a common oper-

ating point. However, under mismatch conditions, the interconnected system must operate at a

single operating point, preventing each cell from operating at its individual MPP[7].

In series-connected strings, this effect is particularly pronounced, as the same current must

flow through all cells. The string current is therefore limited by the cell producing the lowest

current, forcing higher-performing cells to operate away from their optimal point[12]. This re-

sults in mismatch losses, defined as the difference between the sum of the values of individual

cells PMPP and the total power extracted from the string, illustrated in equation 2.5.

Ploss,mismatch =

N
∑

i=1

PMPP,i −Parray | (2.5)

Partial shading creates differences in the irradiance received by the PV cells[12]. Each sec-

tion of the array may receive different irradiance, creating mismatch losses. Partial shading is

caused by physical shadows that block irradiance from reaching sections of the array. This is

the primary cause of mismatch losses in series connected strings.

Partial shading effects and non-uniform irradiance effects can be mitigated through the use

of bypass diodes[12]. These diodes are placed in parallel across groups of cells in reverse-

biased configuration. If this group of cells becomes limited by shading or non-uniform ir-

radiance effects, the current will be maintained, but due to the IV curve characteristics, the

voltage across this group will drop. When the voltage drops below the forward-drop threshold

of the bypass diode, the diode becomes forward-biased and starts conducting. This removes

the under-performing cells from the current path and prevents damage to those cells.

When a bypass diode activates, the PV system loses the power contribution of those under-

performing cells, the output voltage will drop and power is reduced, but damage to those cells

from hot-spot heating is negated. This creates a discontinuity in the IV curve and results in

multiple local maxima occurring in the PV curve[12].

Non-uniform irradiance effects on PV cell IV curves is generally not an issue in conventional

PV systems such as solar farms or roof-tops. PV systems are designed to minimise the effects

of partial shading, and PV arrays are arranged on a single plane. These effects become more

pronounced in automotive systems, with a curved mounting surface and frequent partial shad-

ing events[1]. SMPPT architectures fail to manage these issues and alternative architectures

are required to maintain system integrity.

## 2.3 MPPT Algorithms

An MPPT is required for PV systems to maintain the operating point of a PV array at VMPP

and IMPP[5]. This dynamic operating point requires constant supervision to ensure that the PV

system is extracting maximum power.

An MPPT system consists of three key elements. A DC/DC converter adjusts the operating

point of the PV array. A control unit reads sensor data, runs the MPPT control algorithm, and

generates the required PWM inputs for the DC/DC converter. Sensing circuitry measures PV

voltage and current to provide control feedback[5].

Two core algorithms are perturb and observe (P&O) and incremental conductance. P&O ad-

justs the operating voltage of the PV system and observes a change in power[5]. Incremental

conductance searches for the point in which dP

dV = 0 → dI
dV = −

I
V

, this is where PMPP occurs[5].

These are simple algorithms that are very effective in finding the ideal operating point under

ideal conditions[5]. However, these algorithms assume a single peak in the PV curve, struggle

with partial shading, and are likely to converge to a local MPP[12].

These algorithms assume that the PV curve has a single maximum. Partial shading introduces

multiple PV peaks. P&O and incremental conductance may converge to a local peak rather

than reaching global maxima[12]. This behaviour can be partially rectified by periodically

sweeping the entire voltage range of the PV array and calculating a PV curve to identify peak

locations[12]. This has several issues. Whilst this sweep occurs, power is not being optimally

generated, therefore the sweep can only be ran intermittently to mitigate static partial shading

maxima. In frequently changing conditions, a voltage sweep is likely not help much, due to

maxima occurring for short periods of time.

MPPT algorithms are critical to extract maximum performance from a PV system. More com-

plex algorithms exist that help mitigate local maxima traps and perform faster navigation to the

optimal operating point. These algorithms are based on a concept similar to the two presented

here. The implementation of low-noise sensing and minimal converter ripple is essential for

accurate performance for all MPPT algorithms.

## 2.4 Power Converter Topologies

To control the operating point of a PV system connected to a DC load such as a battery, a

DC/DC converter is used[5]. By adjusting the duty cycle, the converter controls the input

impedance seen by the PV array, allowing the array to be loaded at PMPP[4].

### 2.4.1 Non-isolated Converters

Non-isolated converters can be split into three families. Buck converters are used to lower the

output voltage below the input voltage[4]. Boost converters raise the output voltage above the

input voltage[4]. Buck-boost converters are capable of creating a voltage that is higher than or

lower than the input voltage[4].

Topology Selection

Choosing a topology depends on the voltage of the PV array and the desired output voltage.

If VPV is strictly less than Vbus, then a boost topology is ideal[4]. Likewise, if VPV is strictly

greater then Vbus, then a buck topology is ideal[4]. If the input and output voltages overlap, then

a buck-boost topology may be necessary to ensure proper operation under all conditions[4]. It

is especially important to consider how the voltage of the PV system will change during use

and, if connected to a battery, the wide range of the output voltage.

Boost Converters

For reasons discussed in chapter 3, a non-isolated boost converter topology will be used for the

LV MPPT design in this thesis. Therefore, it is important to understand how asynchronous and

synchronous boost converters work. The principle of operation is similar for most non-isolated

converters, sharing comparable design principles and power loss mechanisms. Figure 2.2 is a

basic asynchronous boost converter.

Principle of Operation

Boost converters are able to increase the output voltage above the input voltage by storing

energy in the inductor[4]. The ratio of Vout
Vin

is determined by the duty cycle of the PWM sig-

nal applied to the gate of the switching element. This relationship is given by equation 2.6.

When the switch is on, current is drawn through the inductor into the ground, storing energy


Figure 2.2: Asynchronous boost converter

in the magnetic field of the inductor. The diode prevents the output from feeding back into the

ground when the switch is on. When the switch turns off, the inductor uses the energy stored in

its magnetic field to maintain the current through it by inducing a voltage across its terminals.

This voltage is added to the input source voltage, creating a larger voltage on the output. The

capacitor stores energy and releases it whilst the switch is on, to prevent an output ripple. The

magnitude of the induced voltage across the inductor is determined by how long the inductor is

charged for; therefore, controlling the switch duty cycle allows for accurate adjustment of the

output voltage.

Vout =

Vin
1−D
[4] (2.6)

Asynchronous and Synchronous Converters

Asynchronous converters can be distinguished from synchronous converters by the existence

of a diode to prevent current from flowing from the wrong source. This diode is the main

source of inefficiency in asynchronous converters because they have a forward-voltage drop.

The power loss due to this drop is given by Pdiode = Iout ·VF. To mitigate the need for a diode,

another switching element is placed instead of the diode. The switching elements are driven

with a complementary pair of PWM signals, preventing back-flow when the primary switching

element is on. Dead-time is injected between the active period of the signals to prevent a direct

short between the output and the negative reference. This is illustrated in figure 2.3.


Figure 2.3: Synchronous boost converter

Ripple Current

Although the principle of boost converter operation is relatively simple, designing an efficient

boost converter involves careful consideration of a variety of features.

The ripple current (∆I) is the difference from peak to peak of the current through the inductor.

It is caused by the switching action of the converter that alternates the inductor between stor-

ing and releasing energy. The ripple current can be estimated using equation 2.7. Increasing

inductance and converter switching frequency reduce ripple current.

∆I ≈

Vin ·D
L · fsw
[4] (2.7)

A large ripple current introduces higher conducted losses in the DC/DC. The conducted losses

are due to P = I

2
RMSR, and although the average current at any given ∆I may be the same, IRMS

will be higher at larger ∆I. A smaller ∆I also allows smaller input currents to be realised before

the inductor enters the discontinuous conduction mode (DCM). DCM occurs when the induc-

tor completely discharges before the next cycle begins, causing non-linearity, larger current

ripple, and increasing inductor losses. Additionally, current ripple can pass through the DC/DC

converter and contribute to higher di
dt seen at the output capacitor, leading to component stress

and contributing to output voltage ripple. Current ripple can also be passed through the MPPT

current sensor leading to inaccurate measurements and noise.

Typically, a design target of ∆I ≈ 10% is chosen. Increasing the inductance and switching

frequency reduces ripple current, but can lead to larger conducted losses from the DC resis-

tance of the inductor, and switching losses in the switching elements.

Ripple Voltage

The voltage ripple (∆V) is the variation in output voltage around it’s average value. Similarly to

the current ripple, it is also caused by the switching action of the converter due to the fact that

the output capacitor must supply energy whilst the inductor is charging. Ripple voltage can be

calculated using equation 2.8.

∆Vout ≈

Iout ·D
C· fsw
[4] (2.8)

A larger ripple will cause an increase in component stress, especially in the output capacitor.

Voltage ripple is an important consideration considering that the boost converter for this thesis

will be directly connected to the internal voltage bus. Introducing a large AC component to a

system of sensitive embedded electronics is undesirable.

A reasonable design target for ∆V is 1−3% of the output voltage. Ripple voltage is dependent

on capacitance and switching frequency. A small ripple voltage is achievable by increasing the

output capacitance. Unlike increasing inductance, increasing capacitance does not introduce

more loss to the system, and the addition of multiple capacitors can reduce the ESR leading to

lower conducted losses.

Switching Frequency

An important part of DC/DC design is choosing the switching frequency. As seen in the dis-

cussion of current and voltage ripple, increasing the switching frequency decreases current and

voltage ripple, resulting in better performance for the overall design. Additionally, as seen in

equation 2.7 and 2.8, increasing the switching frequency also allows for a reduction in the size

of the components whilst maintaining the same performance. This is especially important in

space constrained systems for maximising power density. However, switching losses directly

depend on the switching frequency. Switching losses occur when the switching element tran-

sitions between states. At each transition, some energy is dissipated in the switch as either the

voltage or the current in the switching element is simultaneously high for a brief period. This

is shown in equation 2.9.

Psw ≈

1
2
V I(tr +tf)fsw[4] | (2.9)

Increases in switching frequency also increase gate-charge losses. For a MOSFET switching

element, in every switching cycle, a small amount of energy is lost charging the gate to activate the switch, this is modelled in equation 2.10.

Pgate = QgVg fsw[4] | (2.10)

FET Selection

Choosing the right FET technology can help mitigate switching losses. Silicon MOSFETS are

widely used in power electronics. They are a very mature technology that is fairly low-cost

and gate-driving is simple. This makes them ideal for mass-manufactured products. Although

silicon FETS have low Rds,on indicating low conducted loss, they have relatively slow rise and

fall times, as well as a high gate charge, meaning that the switching frequency is limited to about

20 kHz to 200 kHz[18]. Silicon carbide MOSFETS (SiC) are more costly but can withstand

higher voltages and have far better switching performance[18]. Gallium nitride (GaN) devices

have very low gate charge and output capacitance with extremely fast switching up to 1 MHz,

but are relatively expensive and require sensitive layout considerations[18]. The choice of FET

is extremely application dependent, and there is much more to consider than switching losses

when choosing an FET. Boost component selection reasoning is expanded on in the design

implementation in chapter 4.

### 2.4.2 Isolated Converters

In many systems requiring DC/DC converters, isolation is a strict requirement[4]. This is true

for the Sunswift SR8 HV EV battery, where galvanic isolation to the HV system is required for

safety and to maintain a galvanically disconnected HV system when not in use.

There are a number of topologies that can be used for isolated DC/DC conversion. Some ex-

amples include flyback converters, forward converters, half-bridge converters, and full-bridge

converters[9]. Like non-isolated converters, the choice is application dependent. This section

will briefly examine these converters, as an isolated DC/DC converter is required for this the-

sis design to enable HV battery charging from the PV system. It is important to note that the

isolated DC/DC converter will be connected to the PV system through a LV DC-link (the LV

bus).


Figure 2.4: Flyback Converter

Flyback Converters

Flyback converters use a coupled inductor, as shown in figure 2.4. The input and output voltage

relationship is similar to an inverting buck-boost converter with the addition of a turn ratio,

displayed in equation 2.11.

Vout =

Ns
Np

D
1−D
Vin | (2.11)

The operation is similar to that of the boost converter, where whilst the switch is on, current

flows through the inductor on the primary side, storing energy in the magnetic field (specifi-

cally in the air-gap of the magnetic core)[4]. During this period, the diode on the secondary

side is reverse-biased, a voltage is induced in the secondary winding, but no current flows in

the output. When the switch is turned off, the primary and secondary winding voltages reverse

polarity, allowing the secondary diode to become forward-biased so current can flow through

the output. Like the boost converter, the capacitor supplies energy during the switch ’on’ period

to ensure a stable output.

Flyback converters are very simple to operate and control, and it is possible to achieve very

high output voltages with a high turn ratio. Since the energy is stored in the air-gap of the mag-

netic core, the practical power throughput of this topology is limited before major efficiency

losses and ripples are realised[4].

Forward Converters

Forward converters are similar to flyback converters, but transfer energy whilst the switch is

on and off[9]. Forward converters use a transformer with a single magnetic core, but the pri-

mary side generally contains two sets of windings. When the switch is turned on, energy flows

through the primary winding, inducing a change in flux in the core and, therefore, a voltage

across the secondary winding. The secondary side contains two diodes, one of which will be

forward-biased, allowing current to flow in the output. The same process occurs when the

switch is turned off, except that the secondary winding voltage is inverted, so that the other

diode becomes forward-biased. This operation causes flux to accumulate in the core, leading

to magnetic saturation and zero flux linkage. This is why the primary side has another set of

windings, which apply a reverse voltage to the core during the switch off period, forcing flux

back to zero. This is common, but there are other methods that are used to reset the magnetic

flux in the core.

Forward converters require a slightly more complex design to prevent magnetic core satura-

tion, but can provide a stable output voltage and maintain efficiency at higher power[9].

Bridge Converters

Bridge converters perform DC/DC conversion by creating an AC voltage across the mutually

coupled transformer windings and then rectifying the AC voltage induced on the secondary

winding[4]. These can be separated into full-bridge and half-bridge converters. The name indi-

cates the method of creating an AC voltage. A full-bridge (also known as an H-bridge) uses 4

switches in two totem-poles, with the primary winding connected between the middle of each

pole. The switches are then alternated in two configurations to rapidly switch the voltage polar-

ity on the primary winding, resulting in continuous energy transfer through the transformer. A

half-bridge transformer operates with two switches but can only provide the primary winding

with half of the input voltage. Since more current is needed at a lower voltage for the same

power as a full-bridge converter, half-bridge converters suffer higher conducted losses. A pair

of diodes or synchronous switches is used to rectify the AC voltage, and an LC filter provides

smooth DC output[4].

Although bridge converters are more complex than other converters previously discussed, they offer superior performance characteristics because energy is continuously transferred through

the transformer, rather than being stored and released. This results in higher efficiency, lower

ripple, lower conducted losses, and higher practical power through-put[4].

Summary

This section has discussed a few non-isolated topologies that could be implemented for the

SR8 HV link, and provided practical advantages and disadvantages for each. Although this

section of design is left for thesis B, it will likely involve implementing a full-bridge or half-

bridge converter topology with a synchronous rectifier to maintain maximal efficiency, given

the 750W peak PV power.

## 2.5 Existing Solutions

There are two dominant MPPT architectures, SMPPT systems with interconnected arrays and

distributed MPPT systems. This section evaluates the advantages and disadvantages of each

solution architecture.

### 2.5.1 SMPPT Systems

A single MPPT (SMPPT) system involves having the arrays in a PV system connected in series

and/or parallel and connecting these to an MPPT.

This is the most simple and low-cost solution for integrating an MPPT into a PV system. In-

tegrating an SMPPT system into a DC or AC system is much simpler than other solutions, as

there is only one entry point to consider. It is also highly efficient, more so than many other

solutions, given that the PV system operates under uniform conditions.

The primary drawback of a SMPPT system is the fact that it operates very poorly under non-

uniform conditions. This means that the PV system designer must carefully plan their PV

installation to limit partial shading, difference in panel angles, and other non-uniform factors

to prevent major mismatch losses.

Fundamentally, a SMPPT solution means that the system can use only a single operating point for all PV cells[1]. As soon as one or more PV cells in a series string begin to operate in a

smaller IMPP, the entire string becomes limited by that cell, creating large mismatch losses[7].

Similarly, parallel-connected strings will only be able to operate at a single terminal voltage. If

one string has optimal power output at a different voltage, then that will not be satisfied by the

controller and result in efficiency decreases for that string.

SMPPT systems are ideal for PV installations that generally operate under uniform condi-

tions. They require more planning and suffer major losses in dynamic conditions, but overall

are simpler to implement.

### 2.5.2 Distributed MPPT Systems

Distributed MPPT systems use multiple MPPT modules to segment the PV system and operate

each section with a different operating point. This is in direct contrast with SMPPT systems,

only offering the ability to operate at a single point.

String and Module Level MPPT’s

String and module level MPPT systems refer to having multiple MPPT’s for a single PV sys-

tem, rather than interconnecting all the arrays into a SMPPT. The PV system designer may

choose to have one MPPT per module (an array with multiple strings), one MPPT per series

string, or even choosing to segment strings into smaller strings with individual MPPT’s[1].

As you increase the number of MPPT’s in the system, the cost will rise significantly. There may

also be increased integration risks if multiple MPPT’s are charging the same battery, depending

on the specific MPPT products or the MPPT design. There is also increased mechanical inte-

gration complexity due to a larger number of devices present. However, every additional MPPT

in the system adds additional robustness to dynamic conditions by adding operating point flex-

ibility for the section it controls. It also allows the system to operate with sections at different

angles and to minimise partial shading effects on the global PMPP[13].

DC Optimisers

Some literature refers to string and module level MPPT’s as DC optimisers. This thesis recog-

nises DC optimisers as distributed MPPT method applied on sections of cells inside a series

string.

DC optimisers are small unidirectional or bidirectional DC/DC converters that are connected

to groups of cells inside a series string, illustrated in figure 2.5. These devices can be used in

conjunction with a primary string or module MPPT, or without an external MPPT depending

on the configuration. The devices in figure 2.5 are intended to be used with an external MPPT.

These DC optimisers either inject or extract power from cell groups[10]. The injection case is

intended to support the weak cells in the PV string by injecting current into blocks of under

performing cells, to allow the cell to still contribute some power, and to prevent the string from

becoming current limited. These are used instead of diodes to circumvent the undesired loss in

a diode and to allow the cell to still contribute some power to the system. The extraction mode

is similar and allows the PV string to operate at the current of the weakest cell, and the DC

optimiser extracts the difference in power to prevent mismatch losses. In some configurations,

the final DC optimiser may act as a string based MPPT to mitigate the need for an external

string based MPPT.

DC optimisers are widely regarded as an effective solution to solving mismatch losses in PV

systems. However, they offer considerable integration complexity, especially for existing PV

arrays[1]. DC optimisers require access to intermediate connection points in the PV string and

require arrays without bypass diodes. These PV arrays are commercially available, but the

choice of array will be more limited. The other major drawback is electrical and mechanical

complexity. Integrating multiple DC optimisers per series string means figuring out mounting

locations on the array or nearby, and designing the external harness. In space limited systems,

this is likely not an option.

### 2.5.3 Summary

SMPPT’s, string/module based MPPT’s, and DC optimisers are key MPPT system architectures

that cover a wide range of use cases. SMPPT systems are well-suited to static installations that


Figure 2.5: DC optimiser configuration[10]

have had extensive planning to mitigate partial shading effects. Distributed MPPT’s are ideal

for PV installations with static array differences and for dynamic environmental conditions.

Distributed MPPT systems are very customisable, with the ability to control the operating point

of a single cell, string, or module to improve energy extraction under non-uniform conditions.

They have increased integration complexity, but are far more robust. They are also far more

scalable and reliable due to having multiple control modules[6].

The SR8 PV system will operate under highly dynamic operating conditions, and the PV arrays

are not on a single plane. This analysis indicates that the optimal approach for the MPPT ar-

chitecture is a distributed MPPT architecture. Chapter 3 explores the SR8 system in detail and

proposes a solution to optimise PV system efficiency whilst maintaining an acceptable level of

integration complexity.

# Chapter 3

# Proposed Solution

## 3.1 System Requirements and Constraints

This thesis is focused on developing a MPPT system for the PV arrays on SR8. It is impera-

tive to gain a thorough understanding of the existing electrical architecture of SR8 to design a

system that integrates safely and perform efficiently. The aspects pertaining to the design of an

MPPT system include battery specifications, PV array specifications, and preferred telemetry

format.

Like most EV’s, SR8 utilises a dual battery architecture. A HV 45 kW h, 648 Vnom battery

delivers power to the combined 332 kW motors. A LV 2.3 kW h, 46.8 Vnom battery powers em-

bedded components inside the car, and can remain on whilst the HV battery remains off. The

MPPT must be able to charge both the LV battery and the HV battery. The specifications of

these batteries are described below in table 3.1.

Specification | LV Battery | HV Battery
Cell | INR-21700-P45B | INR-21700-P50B
Configuration | 13S10P | 180S14P
Capacity | 2.34 kW h | 45.36 kW h
Vmin | 32.5 V | 450 V
Vnom | 46.8 V | 648 V
Vmax | 32.5 V | 756 V

Table 3.1: SR8 battery specifications

SR8 has 5 PV arrays positioned on the exterior body panels. These PV arrays are each a

single series string of cells. These are comprised of SunDrive G12-210 SD-HJT cells. These

are heterojunction solar cells and have the highest efficiency for mass-produced solar cells. For

the purposes of this thesis, it is enough to recognise that these have a conventional IV curve.

The key per-cell characteristics are outlined below in table 3.2.

Characteristic | Value
Efficiency | 25.1% ± 0.1%
PMPP | 5.53 W
VMPP | 0.673 W
IMPP | 8.22 A
VOC | 0.744 V
ISC | 8.66 A
Temperature Coefficient of Pmax | ◦C −0.258 %/
Temperature Coefficient of VOC | ◦C −0.27 %/
Temperature Coefficient of ISC | 0.055 %/ ◦C

Table 3.2: Sundrive G12-210 SD-HJT cell characteristics [15]

The PV arrays are positioned on the front (F), roof (R), and back (B) of the vehicle. The

positioning of these arrays is illustrated in appendix 1. There is one large PV array on the front,

with two on the rear panel and 2 on the roof panel. It is important to mention that the arrays

have been segmented such that the curvature of the arrays is minimised within series string.

The effective angle between each array can be as large as 20◦
. The electrical parameters of

each array and G12-210 SD-HJT cell counts are listed in table 3.3. PV cells are arranged in

series for each array.

The maximum power generated by the SR8 PV system is 769 W, however, this number will be

lower because IMPP being limited due to the fact that the arrays are subject to a glass lamina-

tion process to be protected from physical damage whilst in the car. This maximum power will

also not be achieved due to the effective irradiance difference between arrays and losses in the

MPPT and harness.

Array | Cells | V OC [V] | I SC [A] | V MPP [V] | IMPP [A] | PMPP [W]
F1 | 41 | 30.50 | 8.66 | 27.59 | 8.22 | 226.81
BL | 24 | 17.86 | 8.66 | 16.15 | 8.22 | 132.77
BR | 24 | 17.86 | 8.66 | 16.15 | 8.22 | 132.77
R1 | 32 | 23.81 | 8.66 | 21.54 | 8.22 | 177.03
R2 | 18 | 13.39 | 8.66 | 12.11 | 8.22 | 99.58

Table 3.3: SR8 PV array characteristics

The SR8 embedded system communicates using FD-CAN, a modern version of CAN designed

for higher bandwidth and larger payloads. CAN is a bus-based differential communication pro-

tocol which is commonly used in automotive systems. This MPPT design must communicate

with other systems in the car and transmit telemetry over FD-CAN.

The Sunswift Racing solar team has contributed a soft requirement, in the form of being able to

experiment and test their own MPPT algorithms, and test there solar panels off-car. Therefore,

this design should include the ability in firmware to connect to a simple web-based interface to

deploy experimental algorithms and receive telemetry from each MPPT channel.

There is also strict integration requirements that dictate the maximum size and mounting loca-

tion of the MPPT in SR8. The MPPT design including the HV component shall be no more

then 30cm by 20 cm by 10cm. It will also be mounted in a section of the car exposed to water

ingress, so an appropriate IP target must be decided upon and satisfied by this design. Integra-

tion of electronic components in automotive environments requires vibration mitigation, this

was recognised as the primary fault mechanism in the 2025 BWSC race for SR7. Therefore

anti-vibration measures should be taken when mounting the MPPT and for securing internal

components.

## 3.2 Solution Architecture

Gaining an understanding of the system requirements allows an educated decision to be made

for the MPPT architecture. The concept of mismatch losses was introduced in chapter 2. To mitigate mismatch losses caused by differences in effective irradiance angle and due to partial

shading of panels, a distributed MPPT system will be implemented on a single board. For each

PV array (string) on the car, there will be a separate DC/DC converter performing it’s own

MPPT algorithm. This string based approach was chosen to balance integration complexity

with mismatch performance. An alternate solution would be connecting PV arrays in series or

parallel, and using an SMPPT. This solution is simpler but yields much higher losses due to

the difference in effective irradiance between panels and is more susceptible to partial shading

effects.

This distributed MPPT solution will feed power into the LV bus. A micro-controller will handle

software-based protection measures, MPPT control, and output charge state control. There will

also be a HV DC/DC to facilitate HV battery charging when the LV battery is at capacity. This

architecture is illustrated in figure 3.1.


Figure 3.1: Block diagram of solution architecture

## 3.3 Power Stage Topology

In table 3.1 and table 3.3 it can be noted that the minimum LV bus voltage is 32.5 V, the max-

imum PV array voltage is 30.50 V, and the maximum PV array MPP voltage is 27.59 V. This

indicates that the output MPPT voltage is strictly above the maximum MPPT input voltage.

As temperature increases past STC, the input voltage lowers, meaning that this statement is

still valid. It is unlikely for the panels to decrease below STC temperature conditions during

operation.

Due to the relatively low-voltage present in the LV MPPT system, the efficiency and complex-

ity trade-offs for isolation are not feasible. Therefore, a GaN FET based synchronous boost

converter will be used. This topology was chosen due to the input and output voltage ranges,

as well as holding several efficiency advantages over asynchronous boost converters. GaN FET

technology will be used to increase the converter switching frequency whilst limiting switch-

ing losses due to the low gate charge characteristics. This allows for far smaller inductors and

ripple current over other FET technologies such as silicon FET’s.

## 3.4 Control Strategy Overview

MPPT control will be conducted independently for each MPPT channel. Initially, a simple

hill-climbing control algorithm such as P&O will be used to target maximum efficiency in lab-

based conditions. This will be paired with a low-frequency periodic current-sweep to combat

local maxima traps during stationary solar charging. These algorithms will be executed on a

single micro-controller with each converter receiving a complementary pair of synchronised

PWM signals. The micro-controller will also be capable of injecting dead-time. To optimise

converter efficiency, dynamic frequency changes may be incorporated.

The MPPT system will modularise algorithm’s to allow for a web-based interface to select,

modify, and deploy algorithm’s at a user’s request. This means that the MPPT control will be a

two-layer system with a high-level module and optimisation and protection measures operating

at a lower level.

Software over-current and over-voltage protection measures will be used for channel inputs

and bus outputs. The MPPT will monitor battery bus voltage and regulate MPPT output cur-

rent when the battery is approaching capacity. Once the LV battery reaches capacity, the MPPT

will also transition to HV charging to maximise solar energy extraction. This will be done in-

dependently of BMS commands to prevent the battery from over-charging in the event that the

BMS fails or communication fails.

## 3.5 Design Advantages

This design approach was carefully chosen to mitigate the disadvantages associated with exist-

ing solutions and to integrate easily with the existing SR8 architecture.

The multi-channel architecture expresses considerable benefits when compared to a SMPPT

configuration with PV arrays in series or parallel. It allows for the effective irradiance mis-

match between arrays to not bottle-neck power output. This is because MPPT algorithms will

navigate to the most efficient operating point for each PV array, not the combined operating

point. For the same reason, it also mitigates efficiency losses due to partial shading. Another

advantage is that it allows for precise telemetry for each array, facilitating array fault-finding

and testing.

Existing MPPT solutions contain a single output, often to a commonly used battery voltage.

This design incorporates dual outputs. The primary outputs will be used for charging the LV

battery. However, 3 hours of full sun is enough to almost reach LV capacity, therefore a HV

charging system will be incorporated to utilise the PV array when this is the case. This also

means that an external LV/HV DC/DC link will not be required.

An internal MPPT design offers several integration advantages, and allows full control of

telemetry and tight integration with existing systems.

# Chapter 4

# Preliminary Work

This section will detail the design work that has been undertaken in thesis A. This design work

follows the proposed solution in chapter 3.

## 4.1 MPPT Power Stage Design

A core focus of the MPPT design is the LV power stage. This is one of the major factors

that will limit the PV system efficiency. The proposed solution dictated the chosen topology

(Synchronous boost converter) and the reasons why it was chosen. This section will provide

reasoning behind why specific design choices were made. In chapter 2 a detailed analysis

into synchronous boost converters was conducted, revealing key design aspects that this design

takes into consideration.

### 4.1.1 Boost Converter Design Parameters

Ripple Current and Voltage Targets

The first important parameter to choose is ripple voltage, ∆V. To maintain output stability and

ensure sensitive electronics on the LV bus are not effected, a value of ∆V = 2% ·Vout,nom =

0.936 V was targeted. Likewise, ripple current was chosen to be relatively small, at ∆I =

10% · Iin,max = 0.822 A. Inductance, capacitance, and switching frequency will be chosen to

keep these values under these thresholds.

Switching Frequency

Following the ripple threshold selection, a nominal value for fsw should be selected. A value

of 500 kHz will be picked for inductance and capacitance calculations. This value yielded

acceptable efficiency in preliminary testing, which is discussed in a later section. The switching

frequency is likely to be a dynamic variable for efficient operation at light loads.

Inductance Calculation

To keep the LV MPPT design simple, a single MPPT will be designed, and used for all MPPT

channels. Choosing an inductor with multiple values for a single footprint is desired in case

these values can be reduced. Inductance is determined using equation 4.1. Nominal battery

voltages and the MPP conditions of the longest PV string represent an acceptable point in

which to calculate the inductance. With Vin = 27.59 V, Vout = 46.8 V, and D = 0.41. This

yields an inductance of 27.59 µH.

L =

Vin ·D
∆I · fsw

(4.1)

Capacitance Calculation

The required capacitance can be calculated using equation 4.2. Increasing capacitance beyond

the required capacitance has negligible downsides, apart from an increase in size. Therefore,

calculated capacitance will be taken as a rough baseline value when choosing components.

With Pout = 226.81 W, Vout = 46.8 V, Iout = 4.85 A, and D = 0.41, the minimum output capac-

itance is only 4.25 µH.

C =

Iout ·D
∆V · fsw

(4.2)

### 4.1.2 Chosen Components

Following minimum value calculations, components can be chosen that match or exceed those

thresholds.

Inductor Selection

Inductors have multiple variables to consider when making a selection. The most obvious is

inductance. This value will decrease as current increases and builds a magnetic field in the core.

The saturation current indicates this decrease and is typically the value at which the inductance has dropped to 80% of the original value. Since our design will draw high current during nor-

mal operation, Isat should remain above 8.22 A. The core material, size, thermal performance,

DC resistance, and EMI shielding are all factors to consider.

For this design, the Coilcraft SER2211[2] series was identified as a suitable range of induc-

tors to select from. These are flat-wire inductors in a relatively small (22.5 mm) package. They

are magnetically shielded, with a ferrite core for stable inductance over a wide current range.

This series contains 7 inductance values from 3.0µH to 47µH which all use an identical foot-

print, allowing inductance changes after the board has been ordered.

Specifically, the SER2211-333MED 33µH inductor will be used initially for all channels, with

the 27.3µH and 12.3µH versions being purchased as spares for testing. The SER2211-333MED

features a 20% inductance drop at 8.0 A. This is likely the maximum current the inductor will

experience after accounting for the glass lamination losses in irradiance. Therefore, the induc-

tance at this current is roughly 26.4µH. This is slightly less than the target inductance, but

still yields an acceptable input current ripple of about 0.86 A. This ripple is large enough to

cause inaccuracies in the current measurement, so appropriate filters will be considered. This

inductor also has a low DC resistance of 8.95 mΩ.

Capacitor Selection

The capacitor selection was straightforward as a result of the small minimum capacitance re-

quired to reach the target threshold. A total capacitance 48.84µF was chosen in the form of 2

x 22µF capacitors, 2 x 2.2µF capacitors, and 2 x 220nF capacitors. The 22µF capacitor is a

SMT aluminum electrolytic capacitor (EEEFK2A220P[11]) with a 100 V rating. The 2.2µF

capacitors and 220nF capacitors are X7R ceramic capacitors rated to 100 V.

This combination of capacitors was chosen for the ability to provide bulk energy storage to limit

ripple current, and to provide a low ESR path for high frequency voltage transients through the

ceramic capacitors.

FET Selection

Since the switching frequency of this design has been set fairly high to allow the inductor to be

small, an appropriate FET selection must be made. Differences between various FET technol-

ogy is explore in chapter 2, and the decision has been made to proceed with GaN FET’s.

Selection of the GaN FET was based on a combination of gate drive complexity, gate charge,

Rds,on, propagation delay, and drain/source voltage ratings. The Texas Instruments LMG GaN

FET series contains a variety of GaN FET packages. LMG2100R026[16] was chosen as the

GaN FET for this boost design due to the package including an integrated gate driver and dual

FET’s in a totem-pole configuration, greatly simplfying the design and reducing risk of lay-

out error. This device is capable of switching up to 10 MHz, has schmitt triggered logic-level

compatible PWM inputs, 53 A drain current rating, 93 V voltage rating, 2.6 mΩ Rds,on, a gate

charge of 12nC, and rise and fall times of about 35ns.

### 4.1.3 Loss Analysis

There are several loss mechanisms. This section will analyse the magnitude of primary loss

sources such as conducted loss and switching losses, for F1 array conditions.

Conducted Loss

Conduction loss comes from all parts of the boost converter. We can estimate the conducted

loss by calculating the average DC resistance between Vin and Vout. The resistance of traces is

not considered. Losses are summarised in equation 4.3. Assuming an ESR of 1mΩ, Pconducted =

0.78 W at an input current of 8.22A.

Pconducted = I

2
in ·RL +I

2
in ·Rds,on +∆I

2
rms ·ESR[4] | (4.3)

Switching Losses

Switching losses have been previously explained in chapter 2. Using equation 2.9 to cal-

culate the switching loss for the low-side FET, where V = Vout = 46.8 V, I = IL = 8.22 A,

tr = tf = 35 ns, and fsw = 500 kHz, it is found that Psw = 6.7 W. This is large loss, at 2.9% of

the total power. Switching frequency may be adjusted to reduce this loss during testing.

Gate charge loss will not be calculated since the gate driver is packaged with the FET de-

vices. However, the LMG2100R026 datasheet provides the total operating current of VCC at

500 kHz. Therefore Pdriver = VCC ·ICCO = 5 · 15m W = 0.75W.

Loss Summary

The combined losses are given by Ptot = Pconducted +Psw+Pdriver. There are other forms of loss

in the system, but these calculations grant a reasonable expectation for actual efficiency. The

total power loss is Ptot = 8.23 W. At an input power of Pin = 226.81W, the output power is

expected to be Pout = 218.58 with an efficiency of 96.37%. This is a good starting point. This

efficiency will be greater at lighter loads, and optimisations, such as dynamic frequency, will

greatly improve the overall efficiency across the load range.

## 4.2 Auxiliary Circuits

This section will outline preliminary design and selection for a variety of systems across the

design that are necessary to operate the LV MPPT system.

### 4.2.1 Micro-controller

A STM32H743ZIT6[14] micro-controller was chosen to implement control for the 6 MPPT

channels. This was chosen primarily due to the available timer hardware. HRTIM1 is a high-

resolution 16 bit timer with 10 outputs, or 5 complementary outputs. 16 bit 480 MHz resolution

at 500 kHz gives a minimum time-step of 2.08ns and duty cycle resolution of 0.1%, allowing

the MPPT to have fine control over the duty cycle, as well as being able to inject dead time

using software. Investigation and preliminary firmware is required to ensure that the device has

enough program memory to perform 6 MPPT algorithms simultaneously, external RAM and

flash memory may be required.

### 4.2.2 CAN Transceiver

An isolated CAN transceiver was chosen, ISO1044BDR, and implemented according to the

reference schematic. Details can be found in the appendix in the current schematic.


Figure 4.1: MPPT draft layout

### 4.2.3 Power Sensors

There are a total of 12 power sensors across the board, 2 for each channel. Given the number

of sensors, an I2C power sensor (INA238AIDGSR) will be implemented to measure voltage

and current. I2C has the added benefit of increased signal integrity, especially considering the

number of switching elements on the board. They are currently implemented with 15mΩ and

20mΩ shunts. At an input current of 8.22 A and an output current of 4.84 A, these shunts

dissipate 1.48 W. Lowering the shunt value to 5mΩ means that the shunts will only dissipate

0.45 W, which is acceptable. Investigation must be done to find resistors of the right quality,

and ensure the current sensor remains accurate enough for the MPPT algorithms.

## 4.3 Floor Planning

Estimating the total size of the design is helpful for planning on-car integration into SR8. Once

the boost converter components and a majority of the auxiliary components were added to the

schematic, a rough layout was placed with mounting holes to estimate size. This is shown in

figure 4.1. The design is currently 200mm x 100mm x 13mm. This is excluding the enclosure,

which will likely add 20mm in each axis to accommodate panel-mount connectors.

## 4.4 Design Validation and Results

Some basic validation has been conducted for the LMG2100R044. Dr. Ivan Perez-Wurfl and

SPREE student The Vinh Nguyen have developed a LMG2100R044 development board that


Figure 4.2: Input current vs boost efficiency

can be used in buck and boost configurations. They kindly shared this board with the Sunswift

team for evaluation. The author was able to use this board alongside The Vinh Nguyen and

Sunswift members to run some basic tests to determine the efficiency of the LMG2100R044

as a boost converter. This design had a lower inductance of 22µH, and uses a different device

from the same family, but the system is similar to the one that this thesis intends to implement.

Figure 4.2 demonstrates the boost efficiency against the current. This is similar to the efficiency

calculated in the loss analysis above. These results reinforced the design approach this thesis is

using for the boost converters, and the efficiency can be improved on in thesis B.

# Chapter 5

# Project Planning

This thesis can be broken into 5 distinct stages.

1. System requirements and architecture.
2. LV MPPT design and test.
3. Firmware design and test.
4. HV design and test.
5. Performance evaluation and integration.

A detailed flow is displayed in figure 5.1 and these stages are listed with expected dates in the

project timeline in figure 5.2.

The first stage is determining the system requirements that govern design decisions, and us-

ing these to develop an initial architecture. This is now complete and is discussed in depth in

chapter 3.

The second stage is design of the LV MPPT modules. This is most of the way though now,

with major design decisions being made, and the schematic and layout well underway. This

has also been discussed in depth in chapter 4.

In thesis B, the focus will be testing the LV MPPT that should be completed over the term

1 break. In this term, firmware development and HV design of a full-bridge DC/DC converter

will begin. Stages 3 and 4 should be completed around the start of term 3. This leaves the rest


Figure 5.1: Project flowchart

of term 3 to integrating the design into the SR8 electrical and software network, and analysing

the performance of the design for the final report.

Figure 5.2: Project timeline

# Chapter 6

# Conclusion

In conclusion, the goal of this thesis is to develop an MPPT product to be used by the Sunswift

team for SR8. This thesis explores and evaluates possible solutions for optimal PV system

energy extraction under highly dynamic environmental conditions the system is operating un-

der. This report has analysed how PV cells work, and the factors that impact the power they

produce. A variety of converter topologies was also discussed, along with the fundamental

problem of mismatch losses in dynamic PV systems. Existing solutions were analysed to find

strengths and weaknesses that inform the proposed solution. The design philosophy behind the

proposed solution and the reasoning for component and value choices in the preliminary work

was also explored.

The use of a multi-channel distributed MPPT architecture is critical in ensuring the best per-

formance possible for vehicle-mounted PV systems, this thesis will continue to explore this

concept and progress the MPPT design throughout the rest of this year.

# Bibliography

[1] Mustafa Engin Basoglu. Comprehensive review on distributed maximum power point

tracking: Submodule level and module level mppt strategies. Solar Energy, 241:85–108,

2022.

[2] Coilcraft, Inc. SER2211 Series Shielded Power Inductors Datasheet, 2024. Docu-

ment 1084-2. Available: https://www.coilcraft.com/getmedia/3fa53107-10f8-4ffd-a628-

a806422a1bdf/ser2211.pdf.

[3] Illia Diahovchenko, Lubov Petrichenko, Ihor Borzenko, and Michal Kolcun. Application

of photovoltaic panels in electric vehicles to enhance the range. Heliyon, 8(12):e12425,

2022.

[4] Robert W. Erickson and Dragan Maksimovic. Fundamentals of Power Electronics.

Springer, 2001.

[5] T. Esram and P. L. Chapman. Comparison of photovoltaic array maximum power point

tracking techniques. IEEE Transactions on Energy Conversion, 22(2):439–449, 2007.

[6] S. Qin et al. A distributed approach to mppt for pv sub-module applications. In IEEE

ECCE, 2013.

[7] O. Khan and W. Xiao. Review and qualitative analysis of submodule-level distributed

power electronic solutions in pv systems. Renewable and Sustainable Energy Reviews,

76:516–528, 2017.

[8] Roger A. Messenger and Jerry Ventre. Photovoltaic Systems Engineering. CRC Press,

2010.

[9] Ned Mohan, Tore Undeland, and William Robbins. Power Electronics: Converters, Ap-

plications, and Design. Wiley, 2003.

[10] Carlos Olalla, Daniel Clement, Miguel Rodriguez, and Dragan Maksimovic. Architec-

tures and control of submodule integrated dc–dc converters for photovoltaic applications.

IEEE Transactions on Power Electronics, 28(6):2980–2992, June 2013.

[11] Panasonic Industry Co., Ltd. | Aluminum Electrolytic Capacitors (Surface Mount
Type) FK Series Datasheet, 2024. | Document ABA0000C1181. Available:

https://industrial.panasonic.com/cdbs/www-data/pdf/RDE0000/ABA0000C1181.pdf.

[12] H. Patel and V. Agarwal. Maximum power point tracking scheme for pv systems op-

erating under partially shaded conditions. IEEE Transactions on Industrial Electronics,

55(4):1689–1698, 2008.

[13] R. C. N. Pilawa-Podgurski and D. J. Perreault. Sub-module integrated distributed maxi-

mum power point tracking for photovoltaic applications. In IEEE ECCE, 2013.

[14] STMicroelectronics. STM32H743xI/G 32-bit Arm Cortex-M7 480MHz Microcontroller

Datasheet, 2026. DS12110 Rev. 11. Available: :contentReference[oaicite:0]index=0.

[15] SunDrive Solar Pty. Ltd. G12-210 SD-HJT Cell Datasheet, 2025. Version 202502. Avail-

able: https://www.sundrivesolar.com.

[16] Texas Instruments. LMG2100R026 100-V, 53-A GaN Half-Bridge Power Stage

Datasheet, 2024. Available: :contentReference[oaicite:2]index=2.

[17] Marcelo G. Villalva, Jonas R. Gazoli, and Ernesto Ruppert Filho. Comprehensive ap-

proach to modeling and simulation of photovoltaic arrays. IEEE Transactions on Power

Electronics, 24(5):1198–1208, 2009.

[18] Y. Zhang, T. Zhao, and J. Wang. Review of silicon carbide and gallium nitride power

devices for high-frequency applications. IEEE Transactions on Power Electronics,

34(3):2569–2583, 2019.

# Appendix 1

Appendix 1 contains schematic printouts showcasing the current state of LV MPPT schematic

capture. It also contains useful data sheet curves.


Figure 1: Power sensor I2C address


Figure 2: Top-level schematic view of channel 1, 2, and 3


Figure 3: Top-level schematic view of channel 4, 5, and 6

Figure 4: Top-level schematic view of MCU and MCU support blocks


Figure 5: FD-CAN isolated transceiver circuit

Figure 6: LV MPPT boost converter schematic


Figure 7: SER2211 series inductor curves

# Appendix 2


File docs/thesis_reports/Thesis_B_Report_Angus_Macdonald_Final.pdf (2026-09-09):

AND TELECOMMUNICATIONS; by Angus Macdonald; Student ID: z5416730

SCHOOL OF ELECTRICAL ENGINEERING

Thesis B Progress Report

Thesis submitted as a requirement for the degree

Bachelor of Engineering (Electrical Engineering)

Submitted: July 2, 2026
Supervisor: Prof. John Fletcher

# Contents

Contents | 2
Abbreviations | 3
1 Progress Report | 5
2 Reflection | 13
3 Revised Plan | 15
Appendix | 17

# Abbreviations

ADC Analog to Digital Converter

CAN Controller Area Network

FD-CAN Flexible Data-rate CAN

COTS Commercial Off-The-Shelf

EL Electroluminescence

EMI Electromagnetic Interference

FET Field-Effect Transistor

GaN Gallium Nitride

GND Ground

GUI Graphical User Interface

HRTIM High-Resolution Timer

HV High Voltage

I2C Inter-Integrated Circuit

IC Integrated Circuit

ISR Interrupt Service Routine

MCU Microcontroller Unit

MISO Multiple-Input Single-Output

MPPT Maximum Power Point Tracking

NTC Negative Temperature Coefficient

OCP Over-Current Protection

PCB Printed Circuit Board

PCBA PCB Assembly

PV Photovoltaic

SW Switch node

UART Universal Asynchronous Receiver-Transmitter

USB Universal Serial Bus

UVLO Under-Voltage Lockout

# Chapter 1

# Progress Report

## 1.1 Thesis A Summary

The goal of this thesis is to design a multi-channel MPPT solution for the Sunswift 8 solar

vehicle. Given the unique automotive operating environment, understanding the requirements

was critical to creating an optimal design. For this reason, the primary objective of Thesis A was

to understand the requirements, such as bus voltage, panel V/I characteristics, communication

interfaces, and other automotive related requirements. This was discussed thoroughly in the

thesis A report. Furthermore, in thesis A, I took the time to understand loss mechanisms in

synchronous switching converters, MPPT algorithms, and environmental factors leading to PV

perturbations. Using this knowledge, I approached thesis B with an understanding of the design

problem, allowing me to begin the design of a single module testing system.

## 1.2 Single Module Design

After the submission of the thesis A report, I started to develop a solution to characterise

my chosen inductor, GaN switching device, and capacitors. Alongside this, I procured an

STM32H743 Nucleo and designed a JST-GH adaptor board, allowing a single microcontroller

to cleanly attach to 5 of these single modules. This setup is pictured in figure 1.1.

This design integrates two digital INA228 power sensors on the input and output for per-

forming MPPT algorithms and efficiency analysis, alongside a HI/LI interface connected to the

HRTIM channel on the STM32H743. It used a 33µH SER2211 inductor, a LMG2100R026


Figure 1.1: Single module testing setup

GaN half-bridge with an integrated gate-driver, and around 49µF of output capacitance. The

intent was to use this design to de-risk making a large single-board implementation with 5

modules and to uncover any critical design flaws. Originally, the plan was to also implement a

subsection of the final firmware on this microcontroller with 5 modules, but this did not come

to fruition due to issues discussed in later sections.

## 1.3 EMI Fault Diagnosis and Resolution

After receiving this board, I developed a simple UART abstraction interface to allow a GUI to

manipulate the HI/LI duty cycle, pictured in figure 1.2. This used a simple list of predefined

serial headers that contained a single byte command ID, a single byte command size, and then

the data package.

Following this, I uncovered the first design mistake. I had accidentally connected the HI/LI

outputs of the HRTIM channels to the ’HI’ and ’LI’ inputs of the gate driver. However, in a

synchronous boost converter, the ’LI’ or low-side FET is the dominant controlling switch, and


Figure 1.2: GUI for single module testing

the high-side FET is the synchronous diode replacement. Since I made this assumption when

implementing the timers, I caused the output duty cycle to start at 100%, making the output

voltage extremely high when starting. Thankfully, this did not cause any issues and was able to

be rectified by depinning the JST-GH cables and repinning them correctly.

The next major issue with this board is evident in figure 1.2. When the current begins to

increase, the digital power sensors start to rapidly become noisy and even drop-out. This hap-

pened more noticeably at higher switching frequencies, and higher power throughput. This

means that the issues was very likely EMI related, due to the di
dt increasing as fsw increases as

Iout increases. Large di
dt pulses inject noise into the system by injecting voltage through parasitic

coupling inductance.

My first instinct was to probe the I2C bus, and the system ground, to inspect for noise above the

VH threshold of the I2C signals, and for ground bounces. This showed noticeable noise on the

bus with a frequency matching fsw, although the ground seemed relatively unaffected. How-

ever, I noticed that when making the inductor footprint, although I added a keepout directly

under the inductor, this did not extend to the edges of the footprint like it should have. This

meant that I had inadvertently routed the I2C bus directly under the edge of the inductor. To

rectify this, traces were cut and rewired around the edge of the board as seen in 1.3. This did


Figure 1.3: Rerouting I2C traces around inductor

noticeably help and increased the threshold at which I2C sensor dropouts were occurring, but

did not fix the problem.

Following this issue, I then discussed with my supervisor, John Fletcher, to determine what

else could be causing these dropouts. He worked with me to help determine that there could

be a number of factors. We measured the ripple current of the inductor using the input shunt,

and at a nominal input of 8.22A, we found the ripple was as high as ∆I ≈ 4A, saturating the

inductor every cycle. This meant that, due to the placement of the input current sensor (which

was the worst offender), magnetic flux leakage could be causing issues inside the integrated

circuit. This was verified by rotating the inductor position to ensure the flux leakage path did

not intercept the chip. However, this did not fix the issue.

At this point, I had paused fixing this issue to avoid delaying this thesis and began to man-

ually collect results that are discussed in the next section. However, I knew this issue had to

be solved to confidently move to the final implementation. Since I knew it was an EMI related

issue, I began looking harder into the layout of the board. I then realised that although I had

rectified and checked the positive current path out of the I2C sensors (towards the microcon-

troller), I had neglected to check the return current path. I then realized that I had forgotten

to stitch the ground plane surrounding the INA sensors, forcing the return current path right

through the SW node of the FET (effectively, the current path was using the thermal GND vias

of the FET). This return path is seen in figure 1.4. This would explain why the bottom INA228

sensor was seeing more dropouts than the top, since the return current path is also routed under


Figure 1.4: Return current path illustrated on layout

the inductor. To test this hypothesis, I cut the ground plane in multiple locations and soldered

wires directly from the chips to the left-side of the board that had a more direct path to the mi-

crocontroller, pictured in figure 1.5. This solved all dropout issues and gave me the confidence

to move to the final hardware implementation.

## 1.4 Power Stage Testing Results

Whilst I was still resolving the EMI issue present in these single module test boards, I was still

able to manually collect data using the bench supply and load. Both of these devices are able

to measure the supplied voltage and current to the nearest mV and mA respectively. This test

setup is pictured in figure 1.6.

Using voltage sense wires, I was able to bypass the effects of voltage drop on the connect-

ing cables, and extract some positive results that validated this converter approach. For the first

test, I collected efficiency data at a fsw of 300kHz with a constant duty cycle. The results are

show in figure 2. It can be seen that the peak efficiency in this basic switching configuration is


Figure 1.5: Return current path rework


Figure 1.6: Single module testing setup about 98%, which is a good result and gives confidence with this converter design for the final

implementation.

I also collected data for a frequency sweep, keeping a constant current of 7A and a constant

duty cycle. This gave a peak efficiency of about 98.4% at 200kHz, although the current ripple

at this frequency may be unacceptable for the MPPT controller to perform accurately. The

results for this test are found in figure 3.

In comparison to my Thesis A prediction of 96.5% based on calculated switching and con-

duction losses, these results are higher. This is possibly due to having a shorter rise and fall

time than expected on the FET’s, leading to reduced switching losses. It is important to note

that due to measurement error in the supply and load, as well as shunt tolerance, the peak effi-

ciency measurement must be taken as an estimate rather than an absolute value.

After completing testing and debugging for the single module test boards, I was happy to move

to the final hardware implementation. The rest of thesis B, up until the writing of this report,

has focused on this design.
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

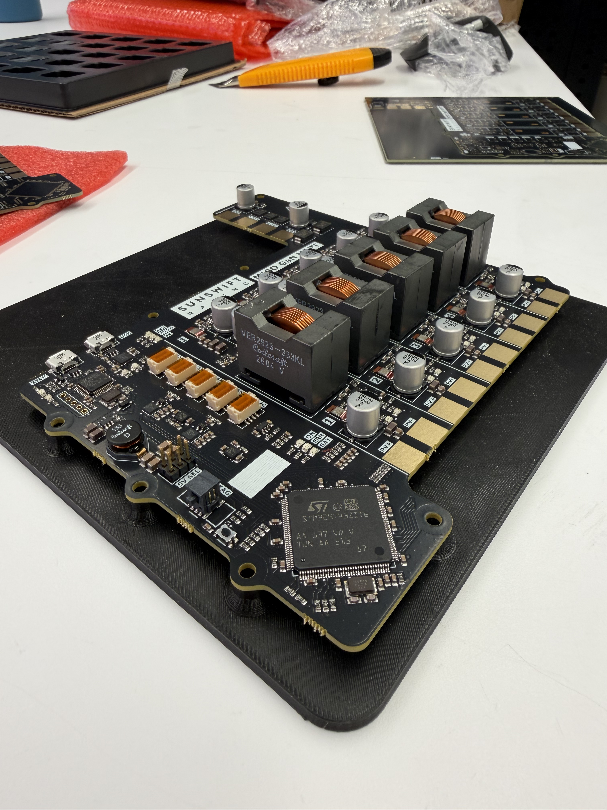
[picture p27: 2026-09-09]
docs/photos/board.jpg

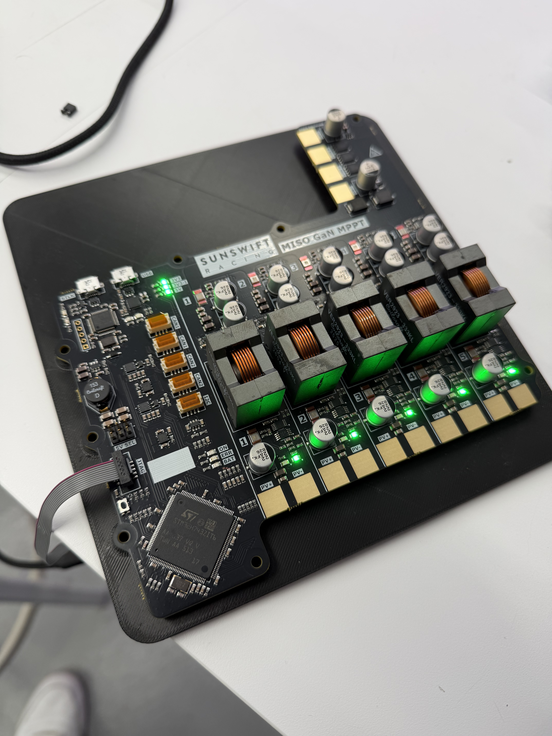
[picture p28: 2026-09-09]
docs/photos/board_with_lights.jpg

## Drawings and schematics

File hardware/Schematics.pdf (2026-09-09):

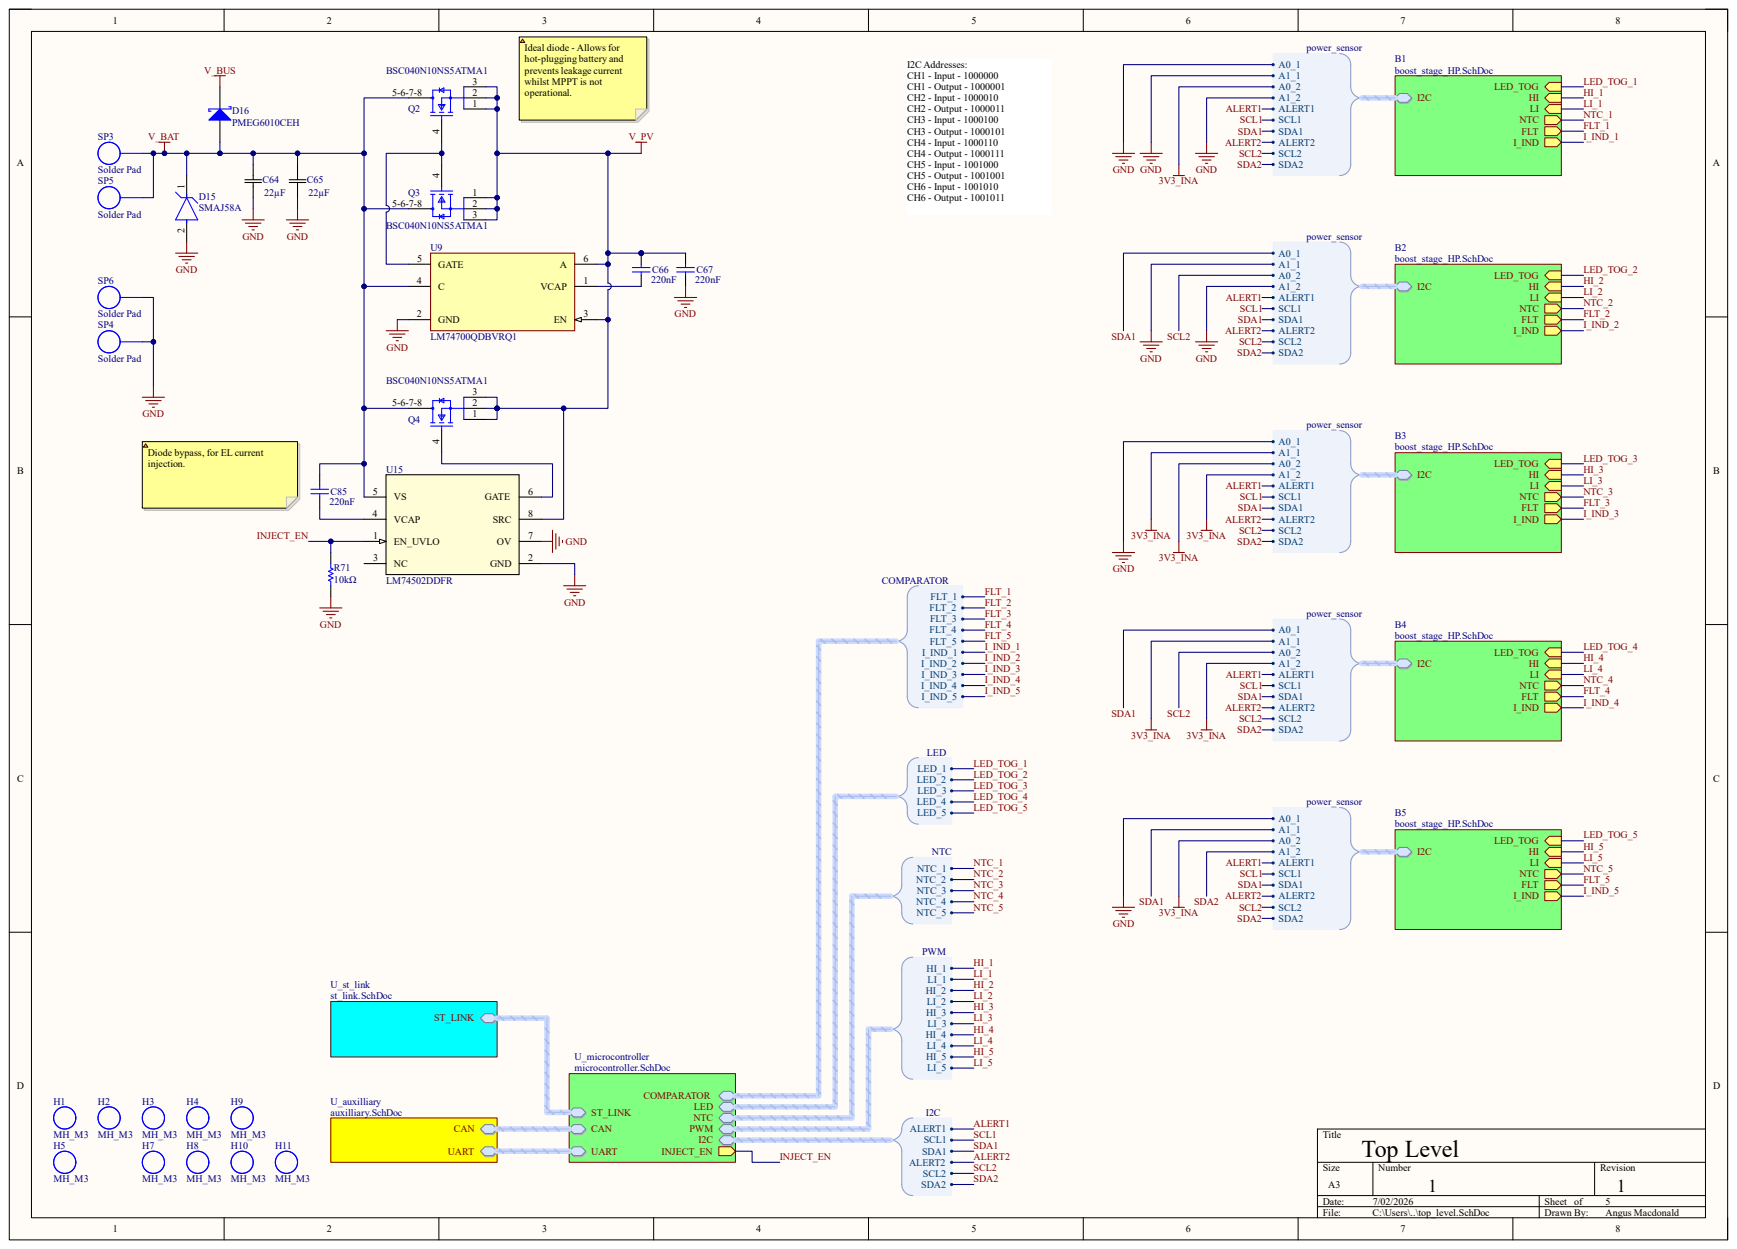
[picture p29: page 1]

Ideal diode - Allows for
hot-plugging battery and
prevents leakage current
whilst MPPT is not
operational.

Diode bypass, for EL current
injection.

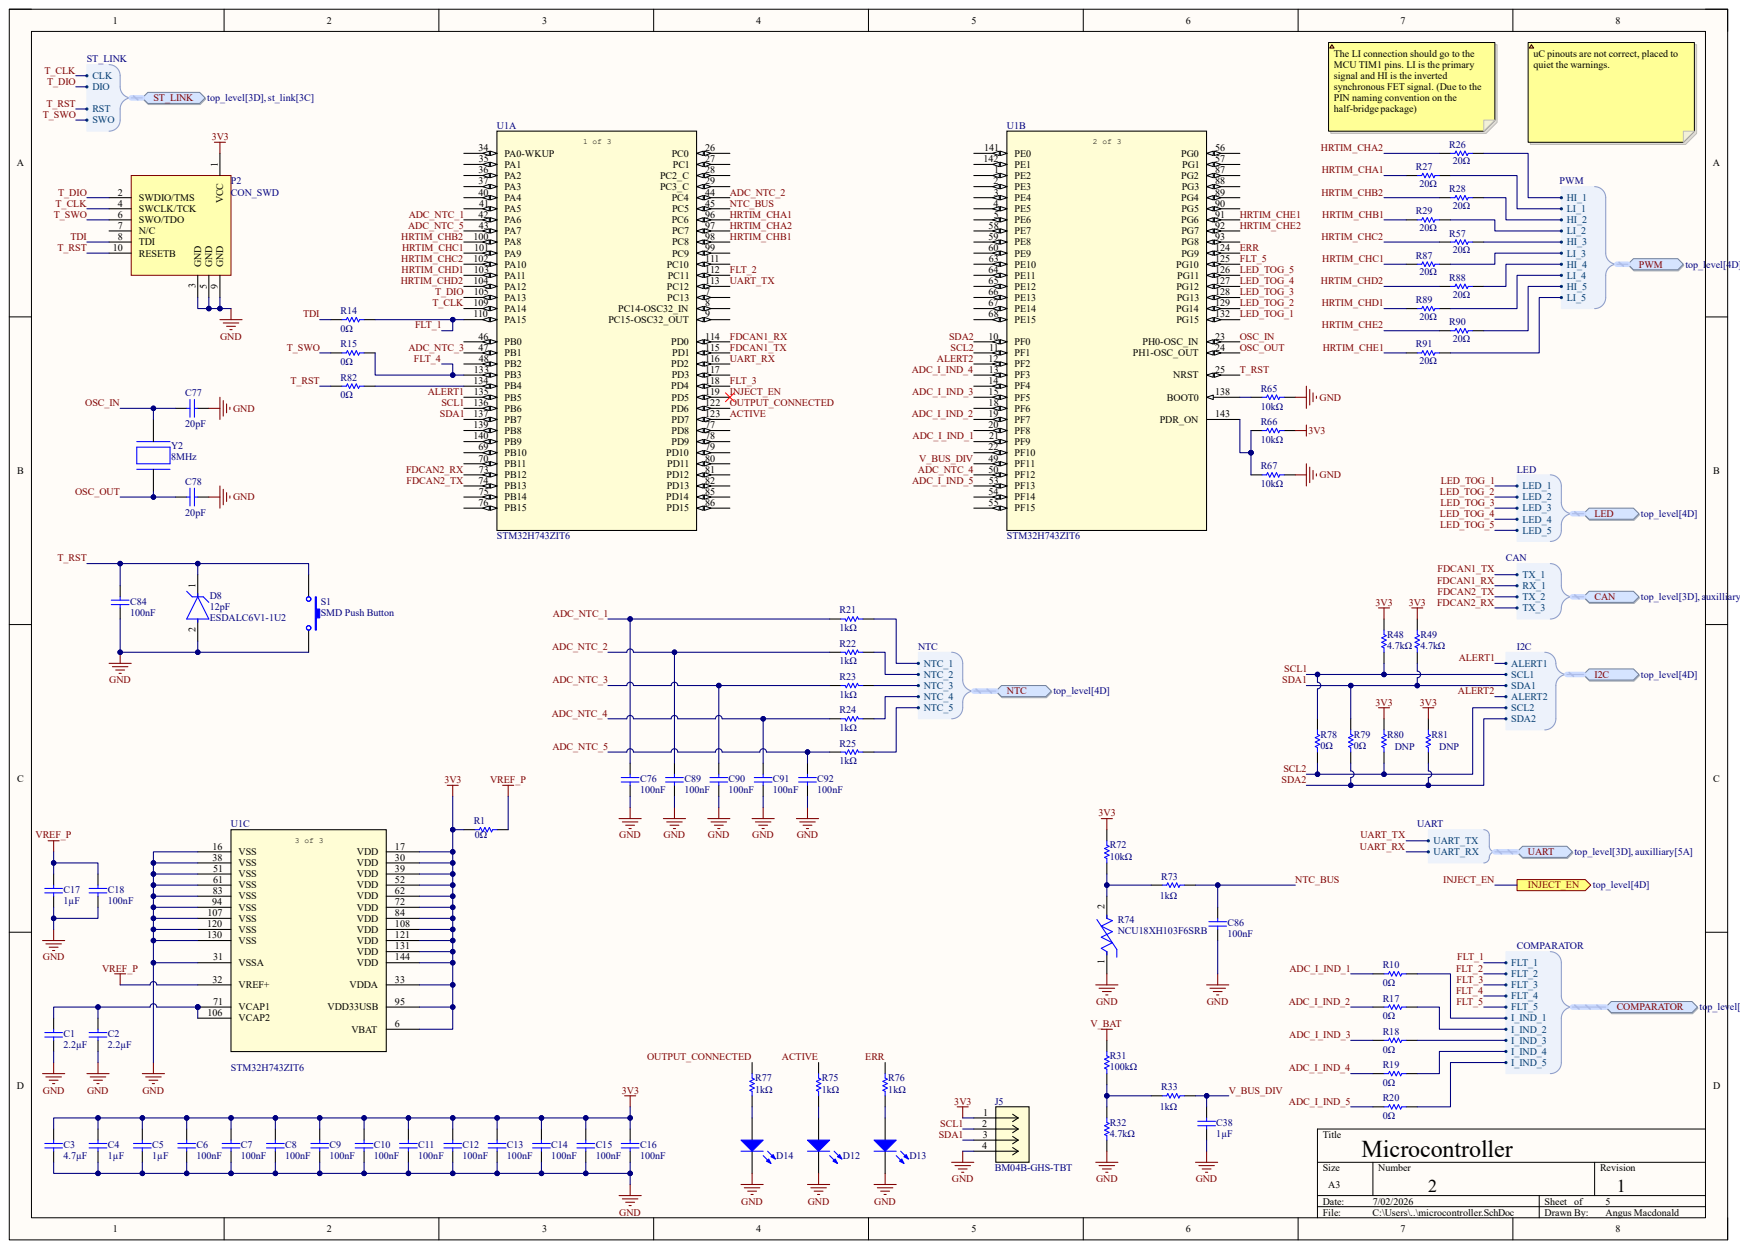
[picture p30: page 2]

The LI connection should go to the
MCU TIM1 pins. LI is the primary
signal and HI is the inverted
synchronous FET signal. (Due to the
PIN naming convention on the
half-bridge package)

uC pinouts are not correct, placed to
quiet the warnings.

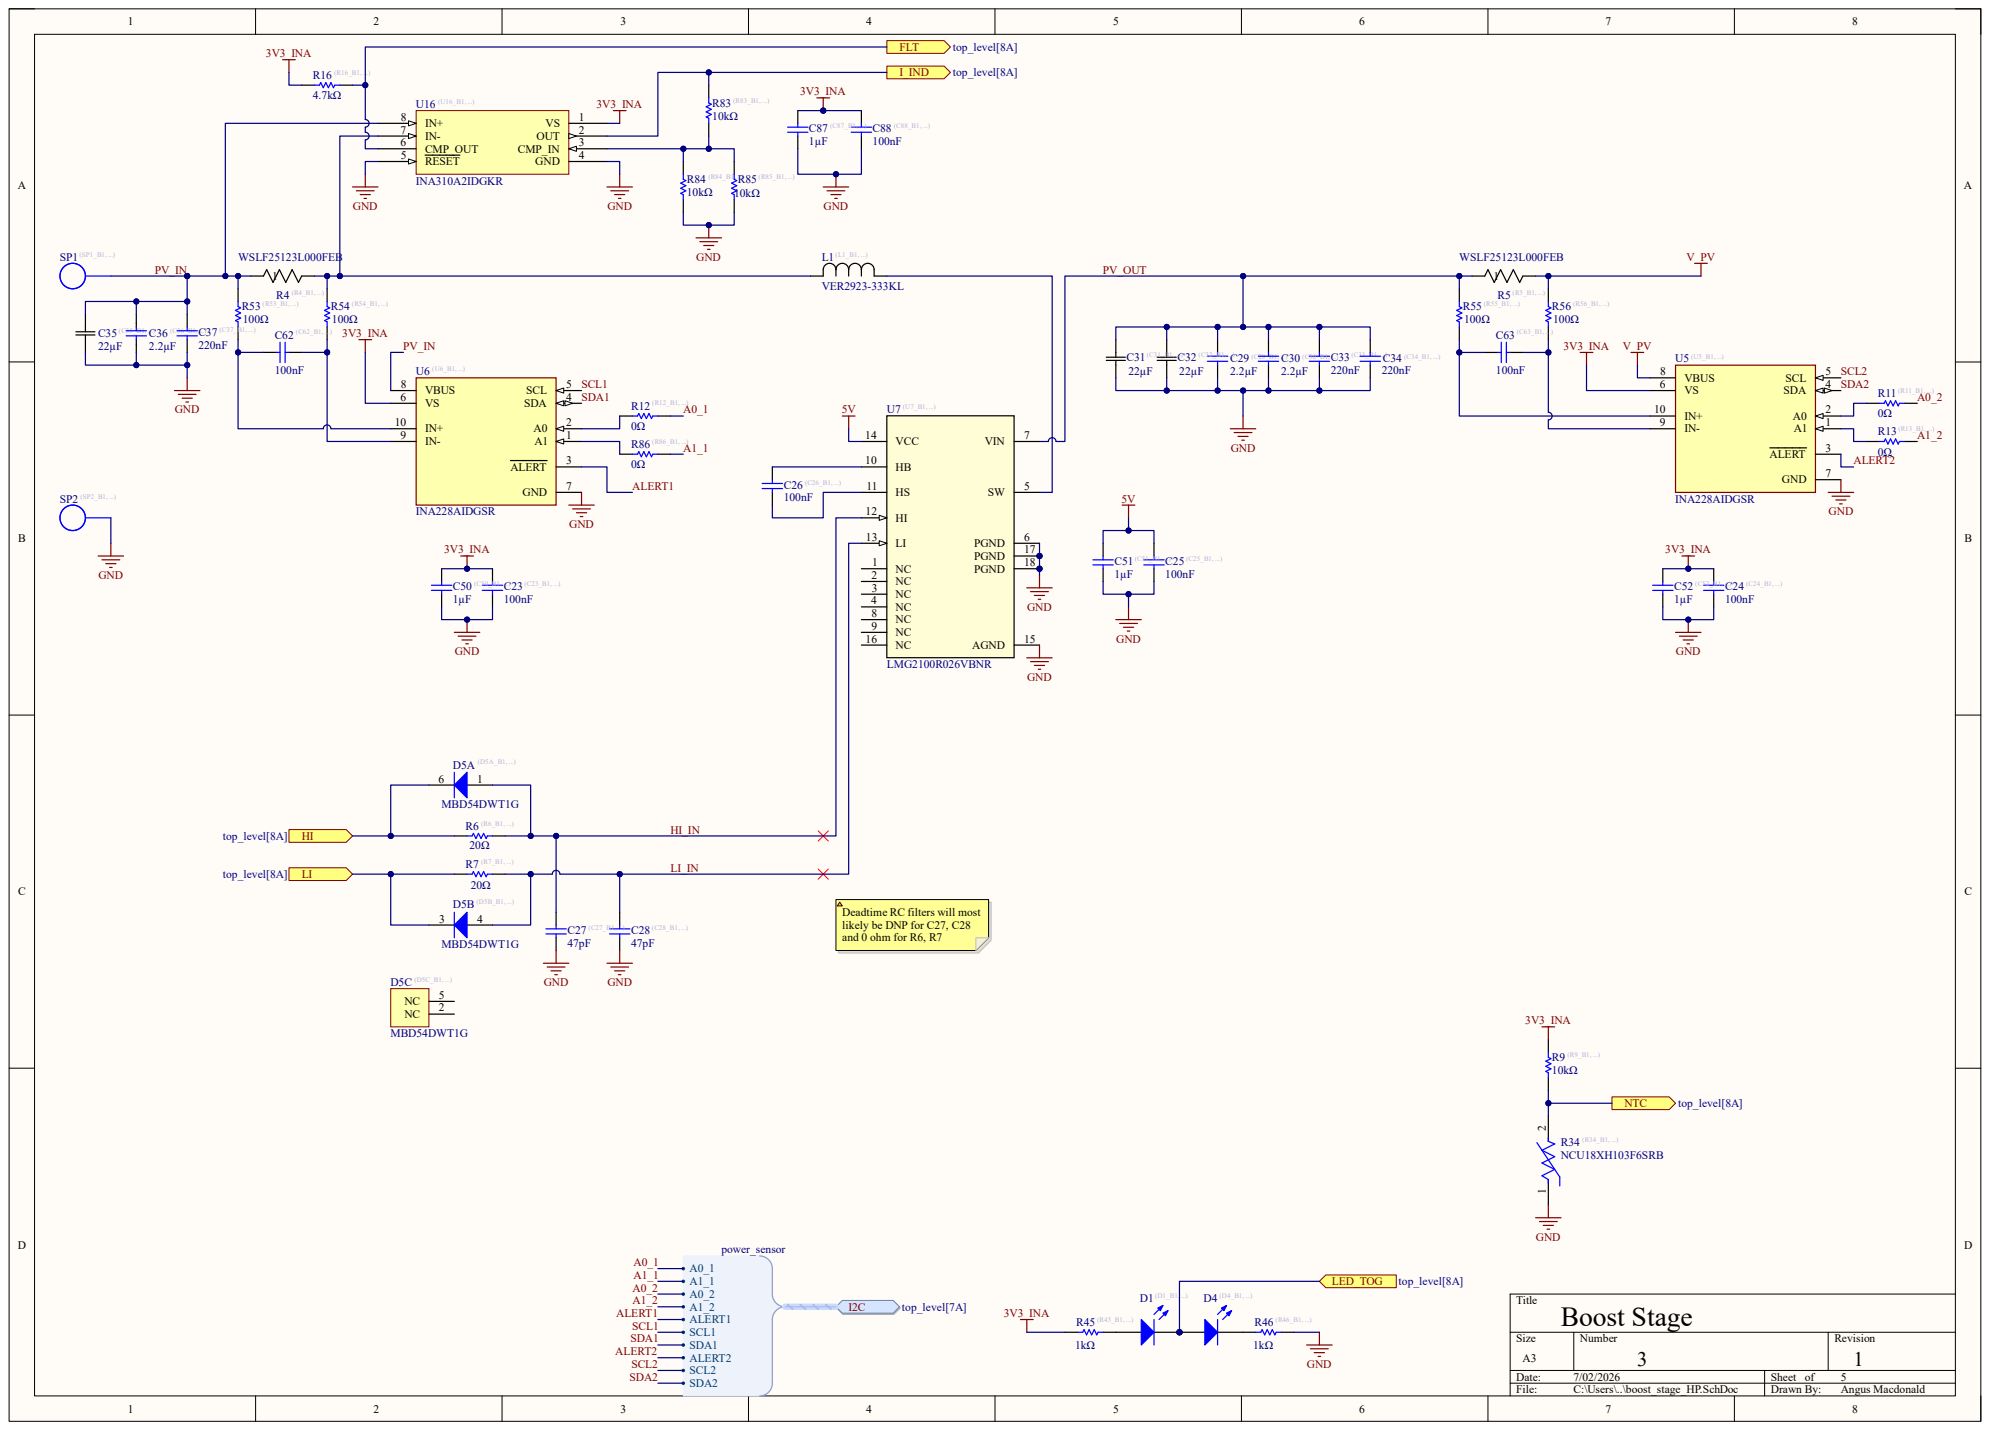
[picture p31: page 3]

Deadtime RC filters will most
likely be DNP for C27, C28
and 0 ohm for R6, R7

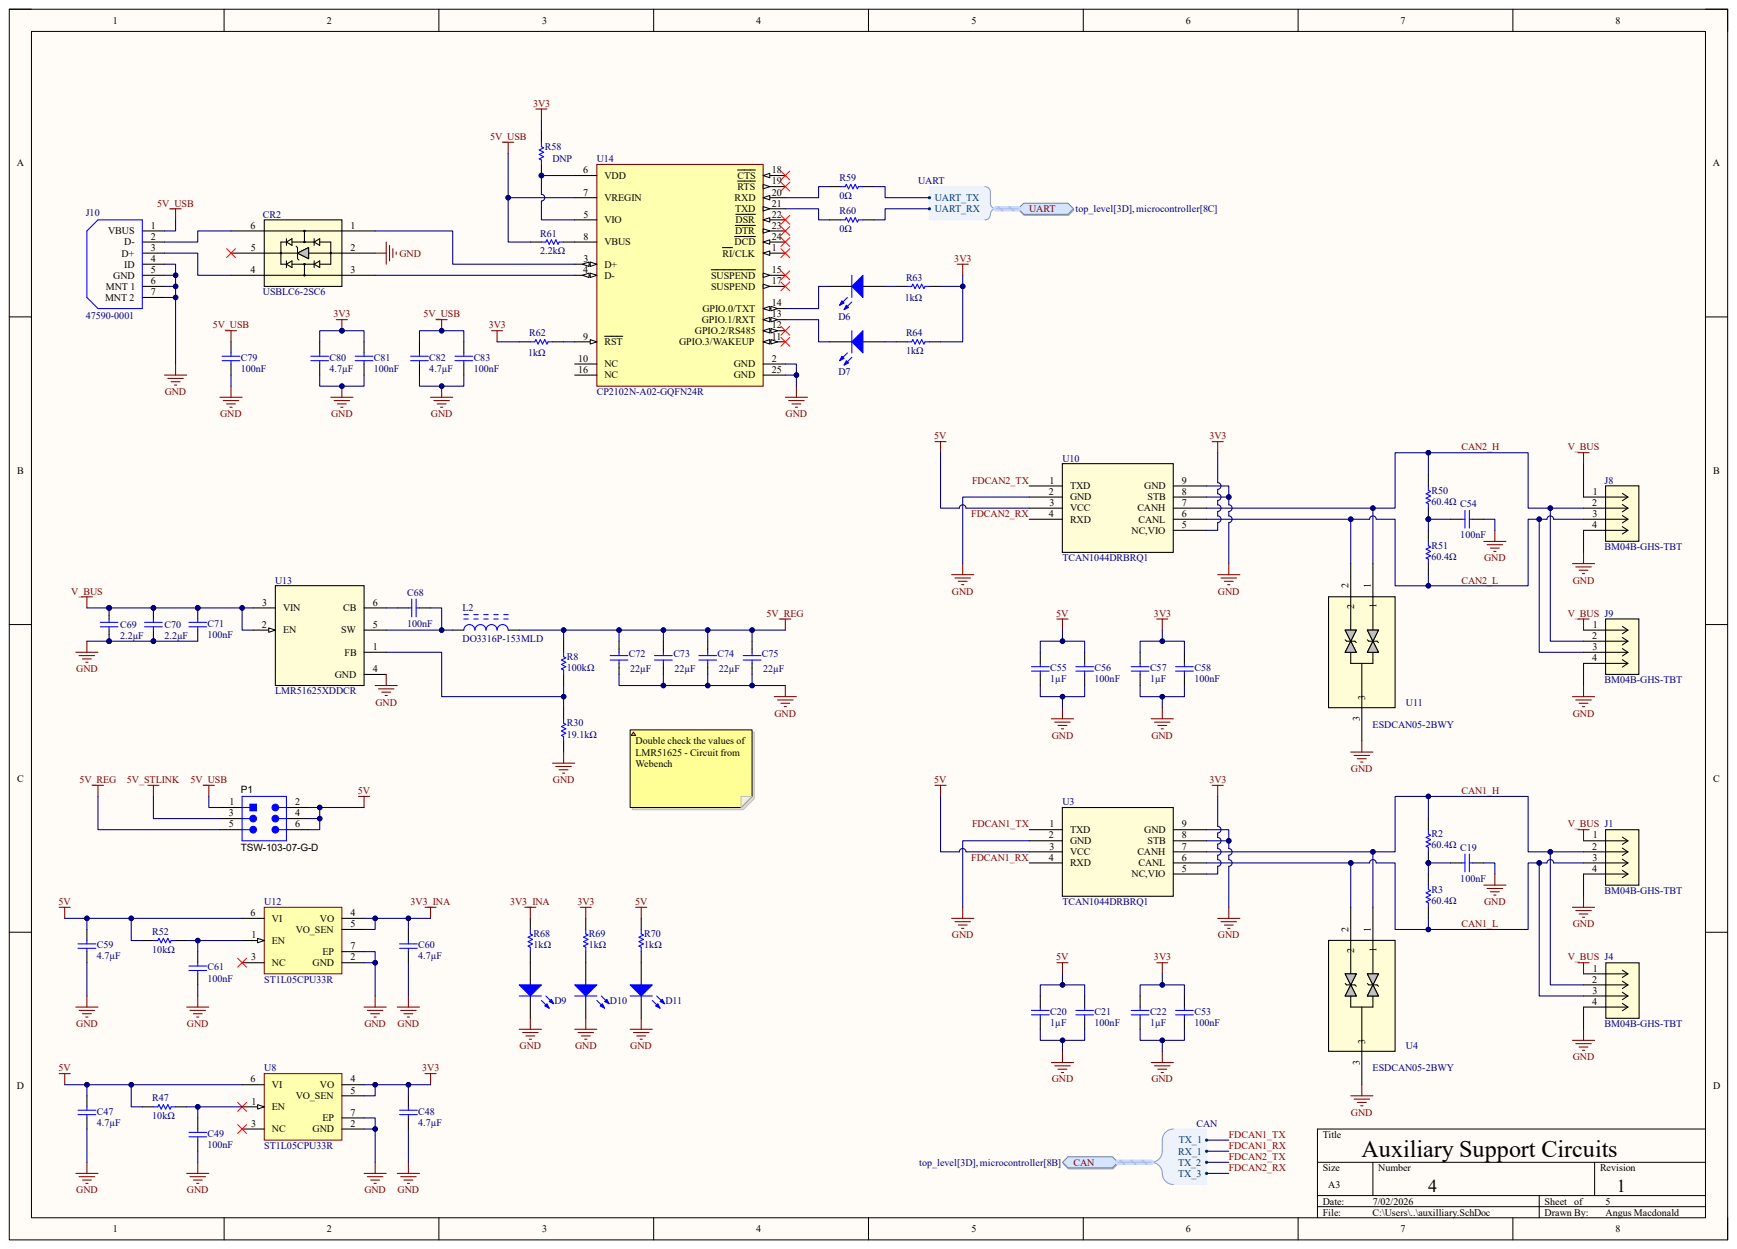
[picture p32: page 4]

Double check the values of
LMR51625 - Circuit from
Webench

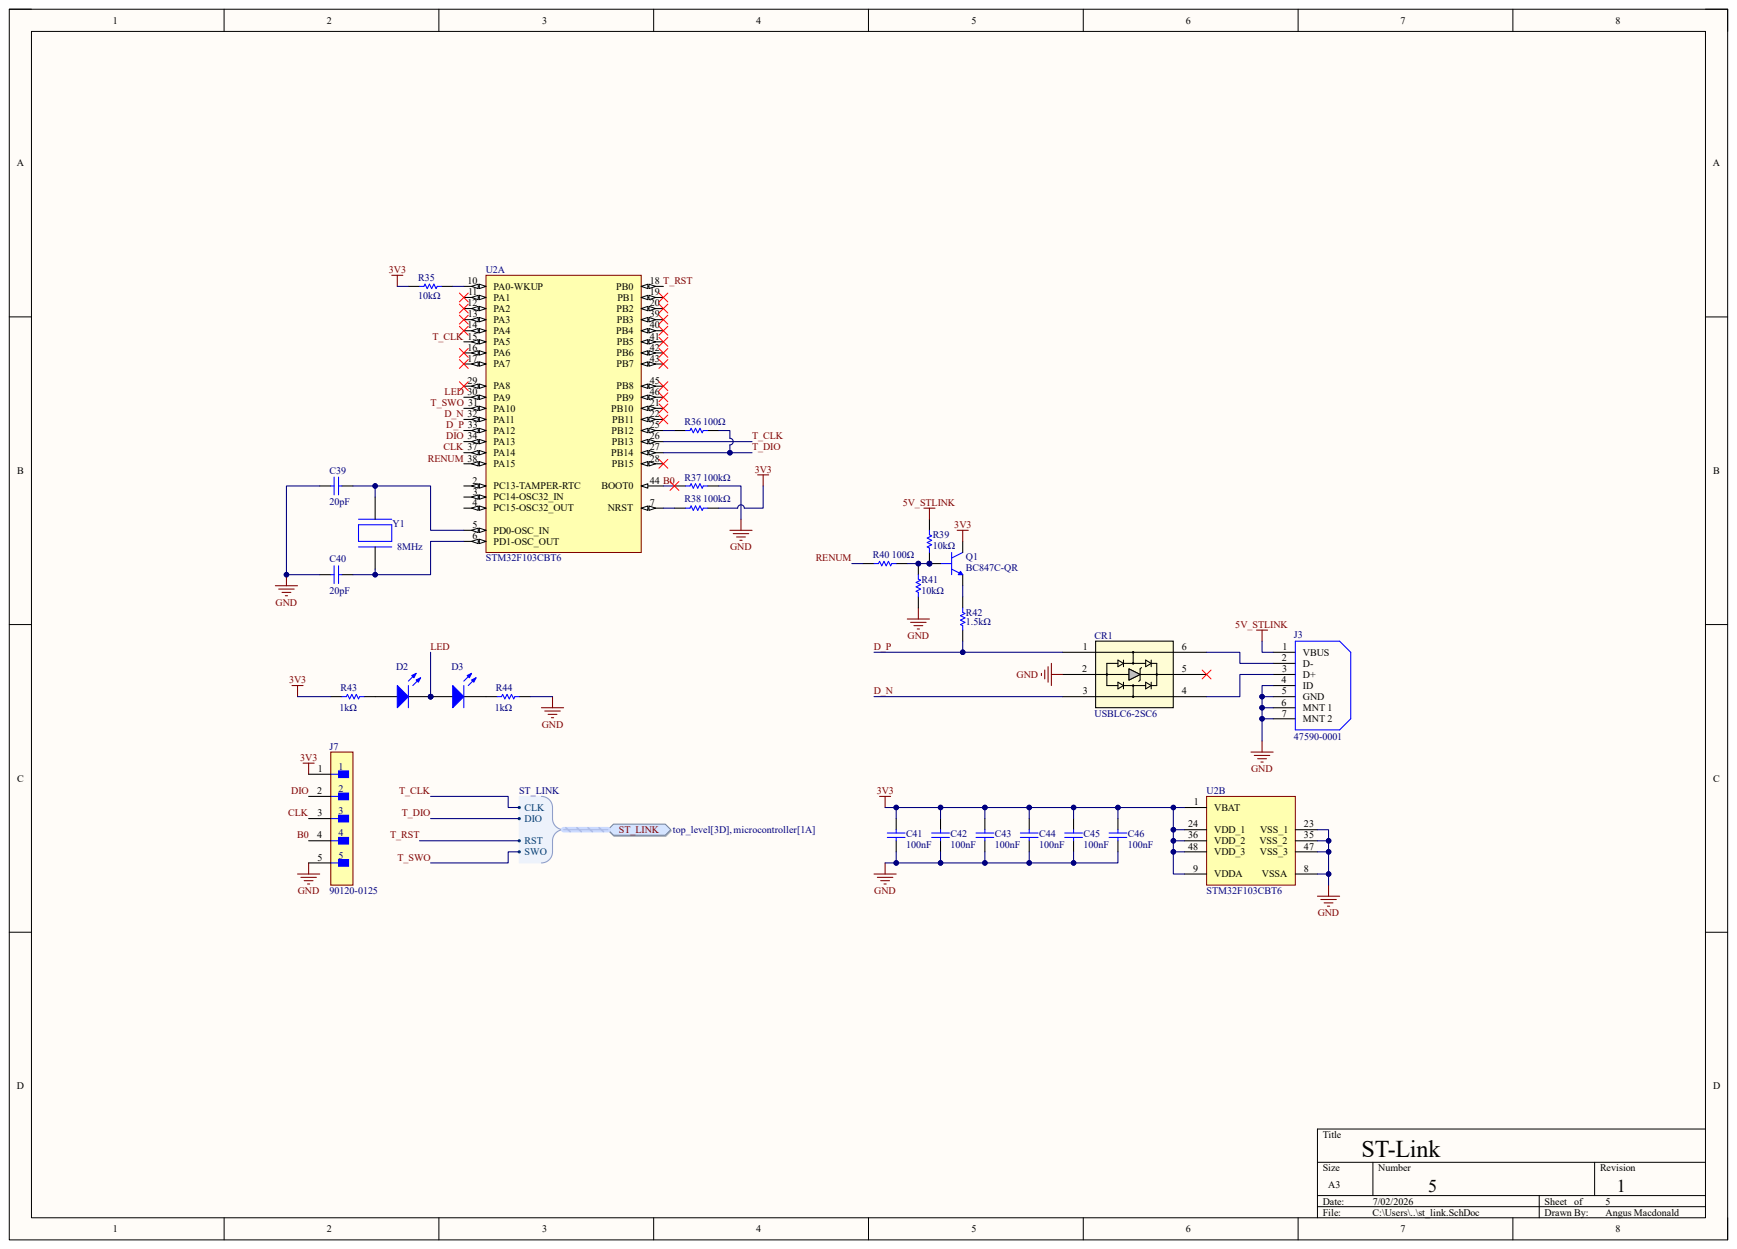
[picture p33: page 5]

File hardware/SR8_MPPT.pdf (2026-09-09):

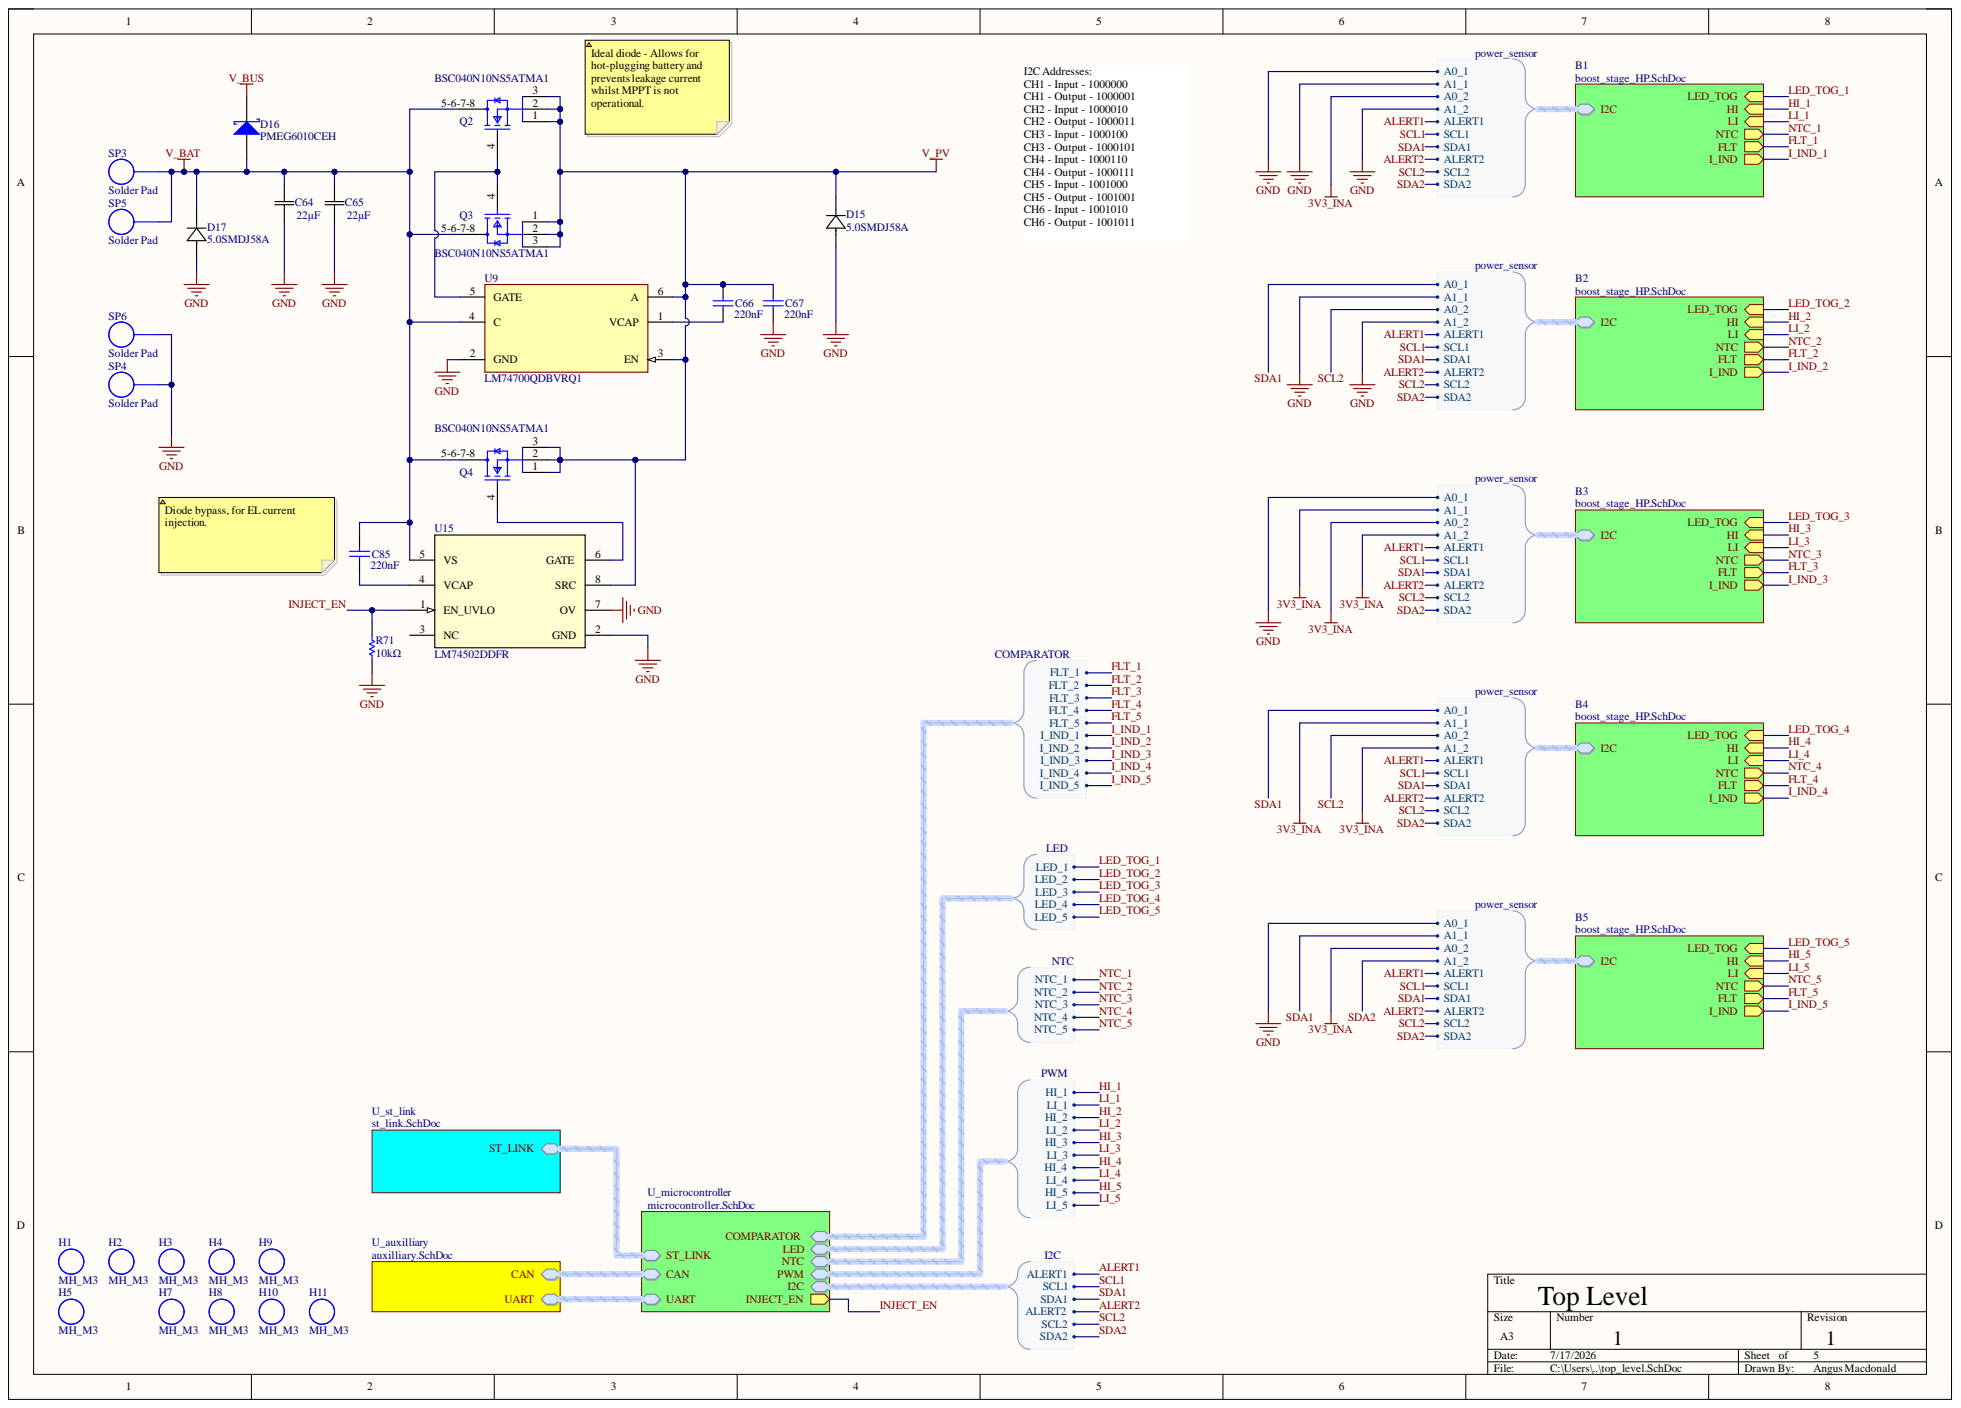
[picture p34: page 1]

BSC040N10NS5AT

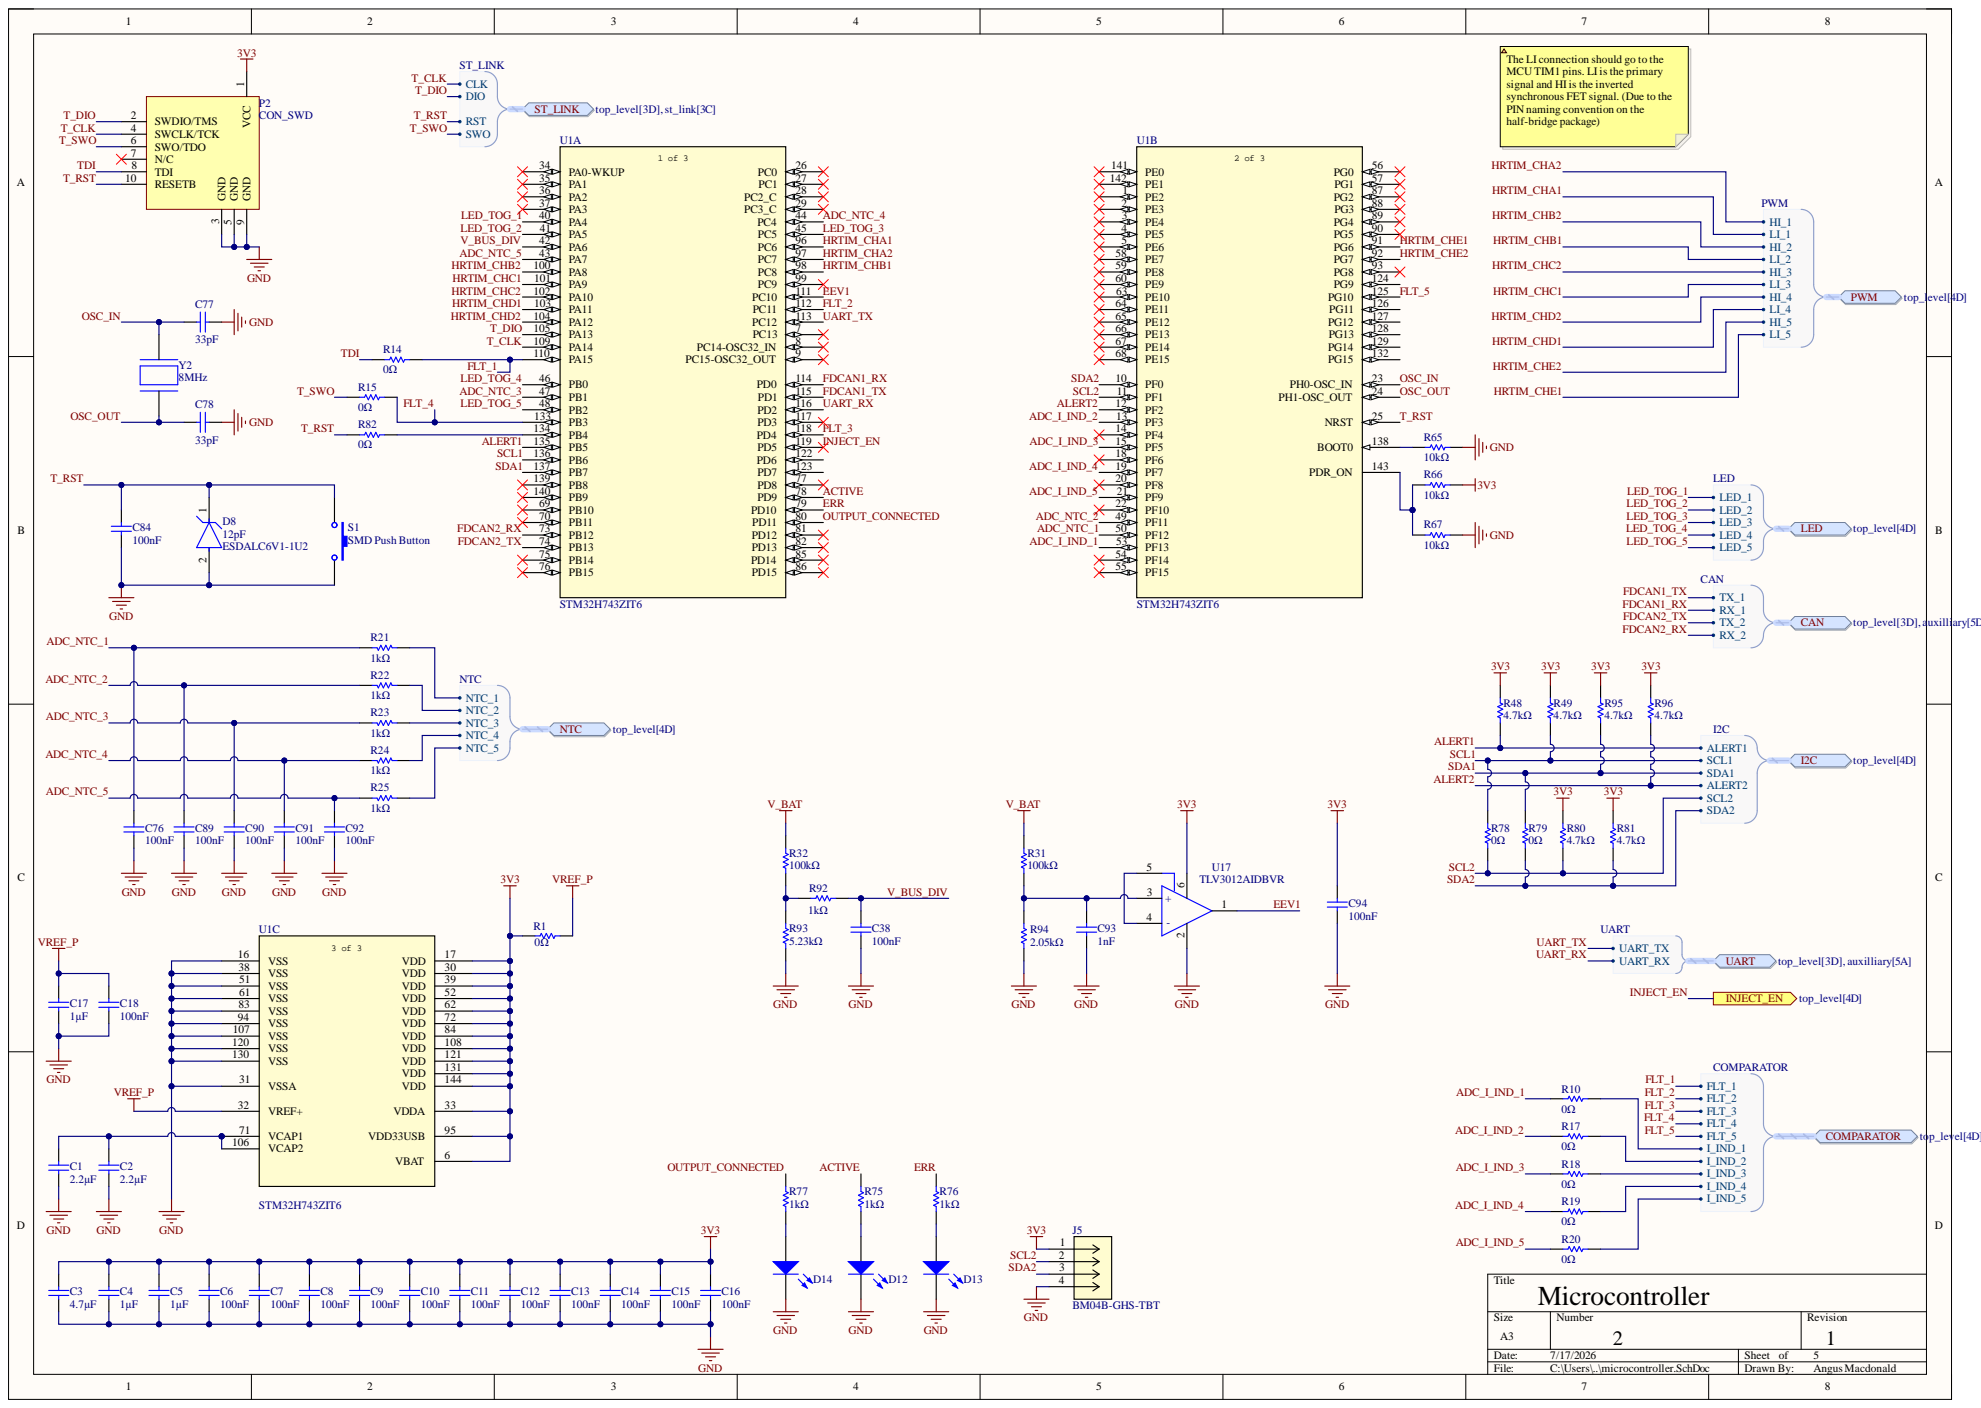
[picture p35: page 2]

The LI connection should go to the
MCU TIM1 pins. LI is the primary
signal and HI is the inverted
synchronous FET signal. (Due to the
PIN naming convention on the
half-bridge package)

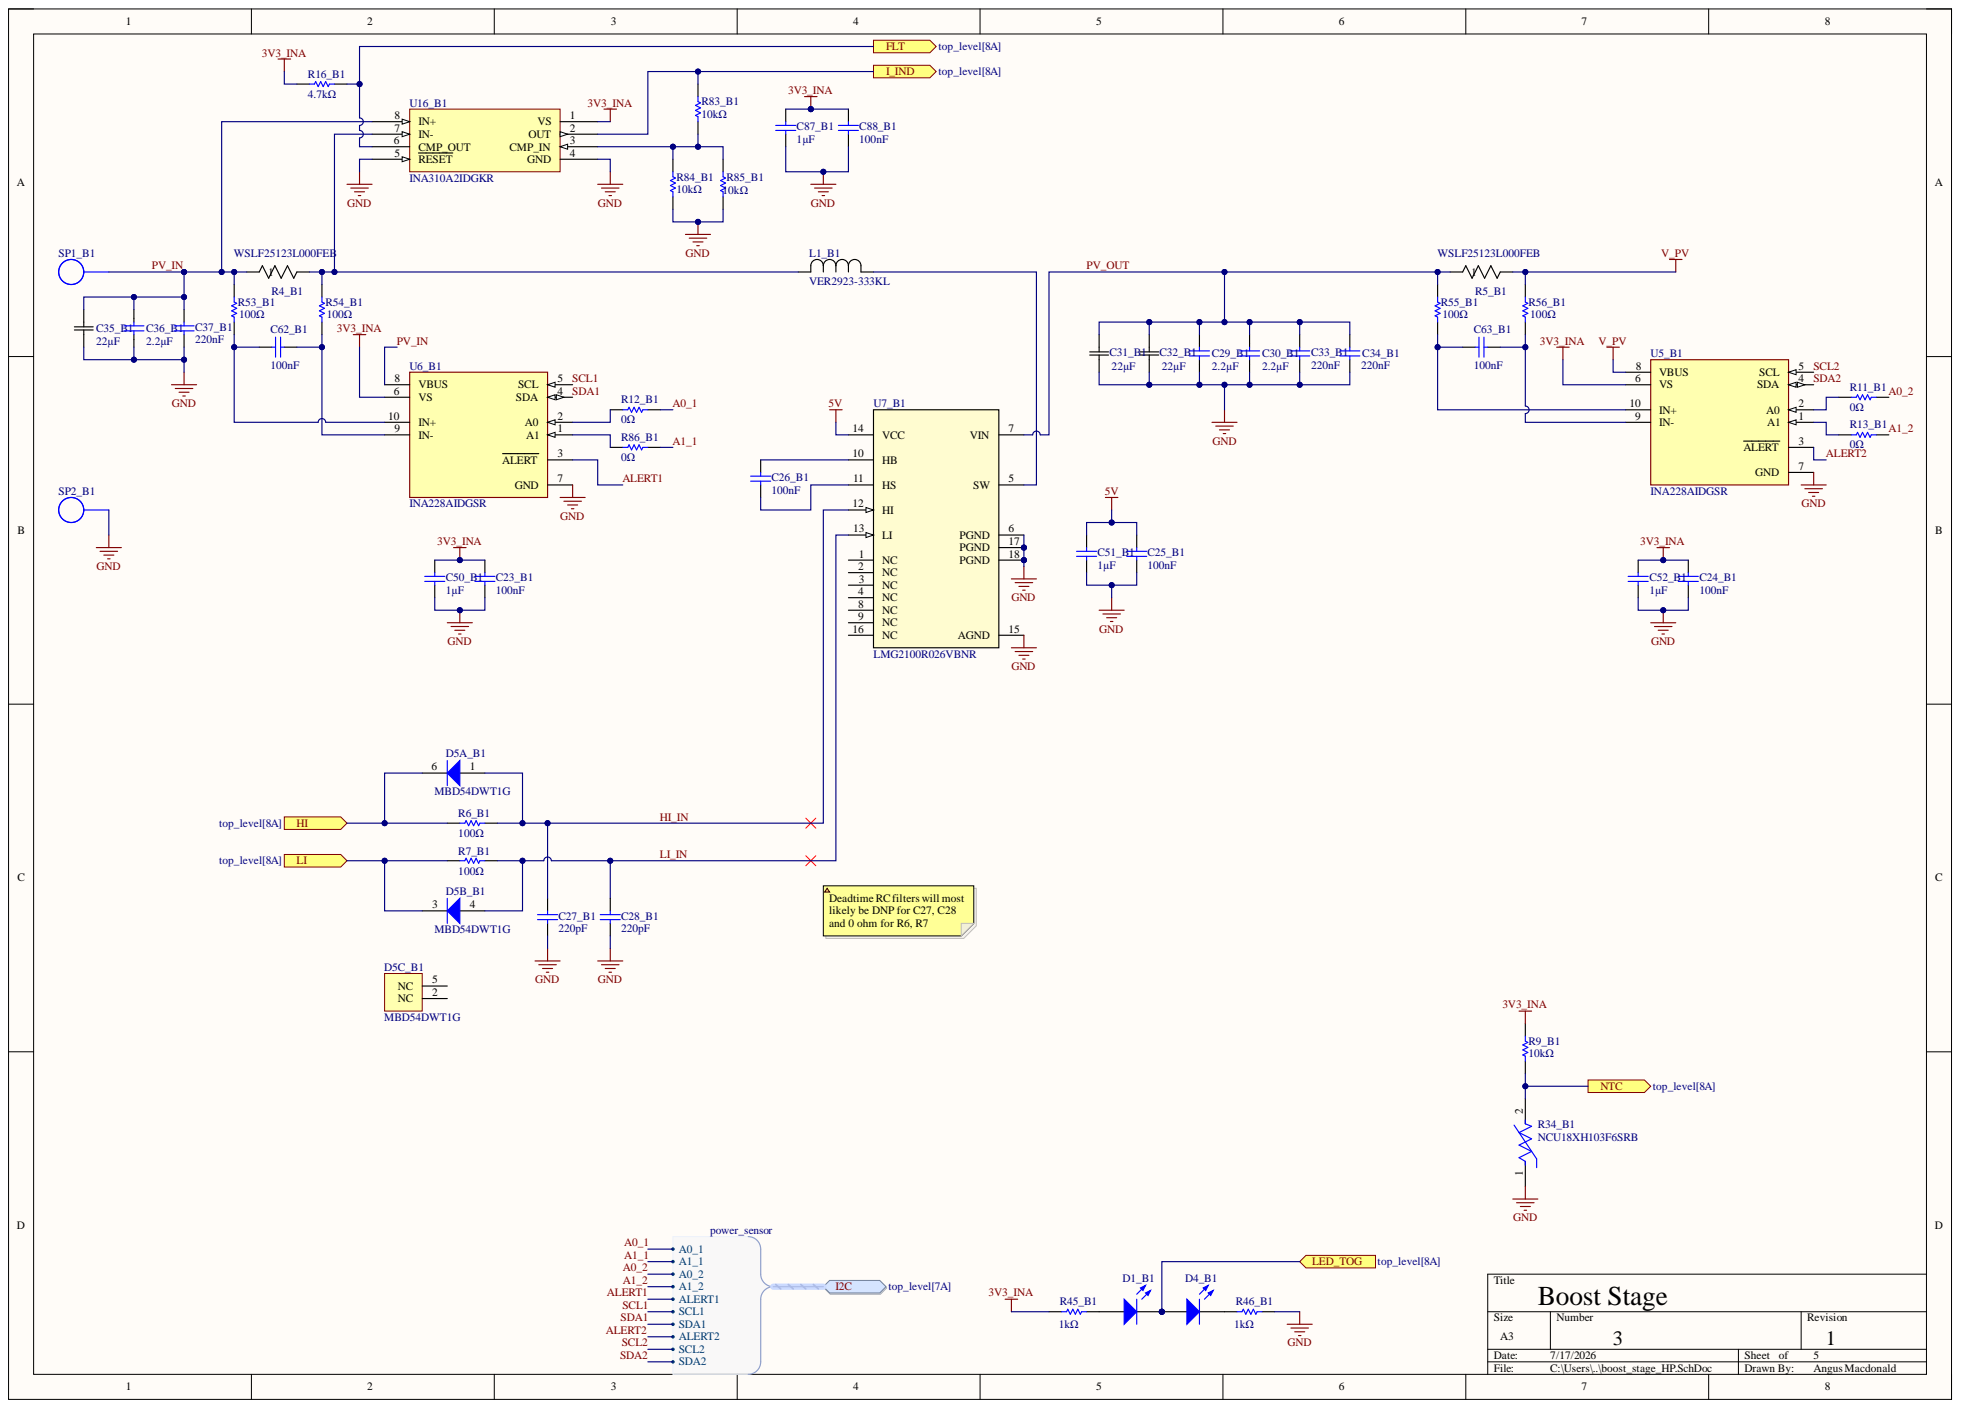
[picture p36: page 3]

Deadtime RCfilters will most
likely be DNP for C27, C28
and 0 ohm for R6, R7

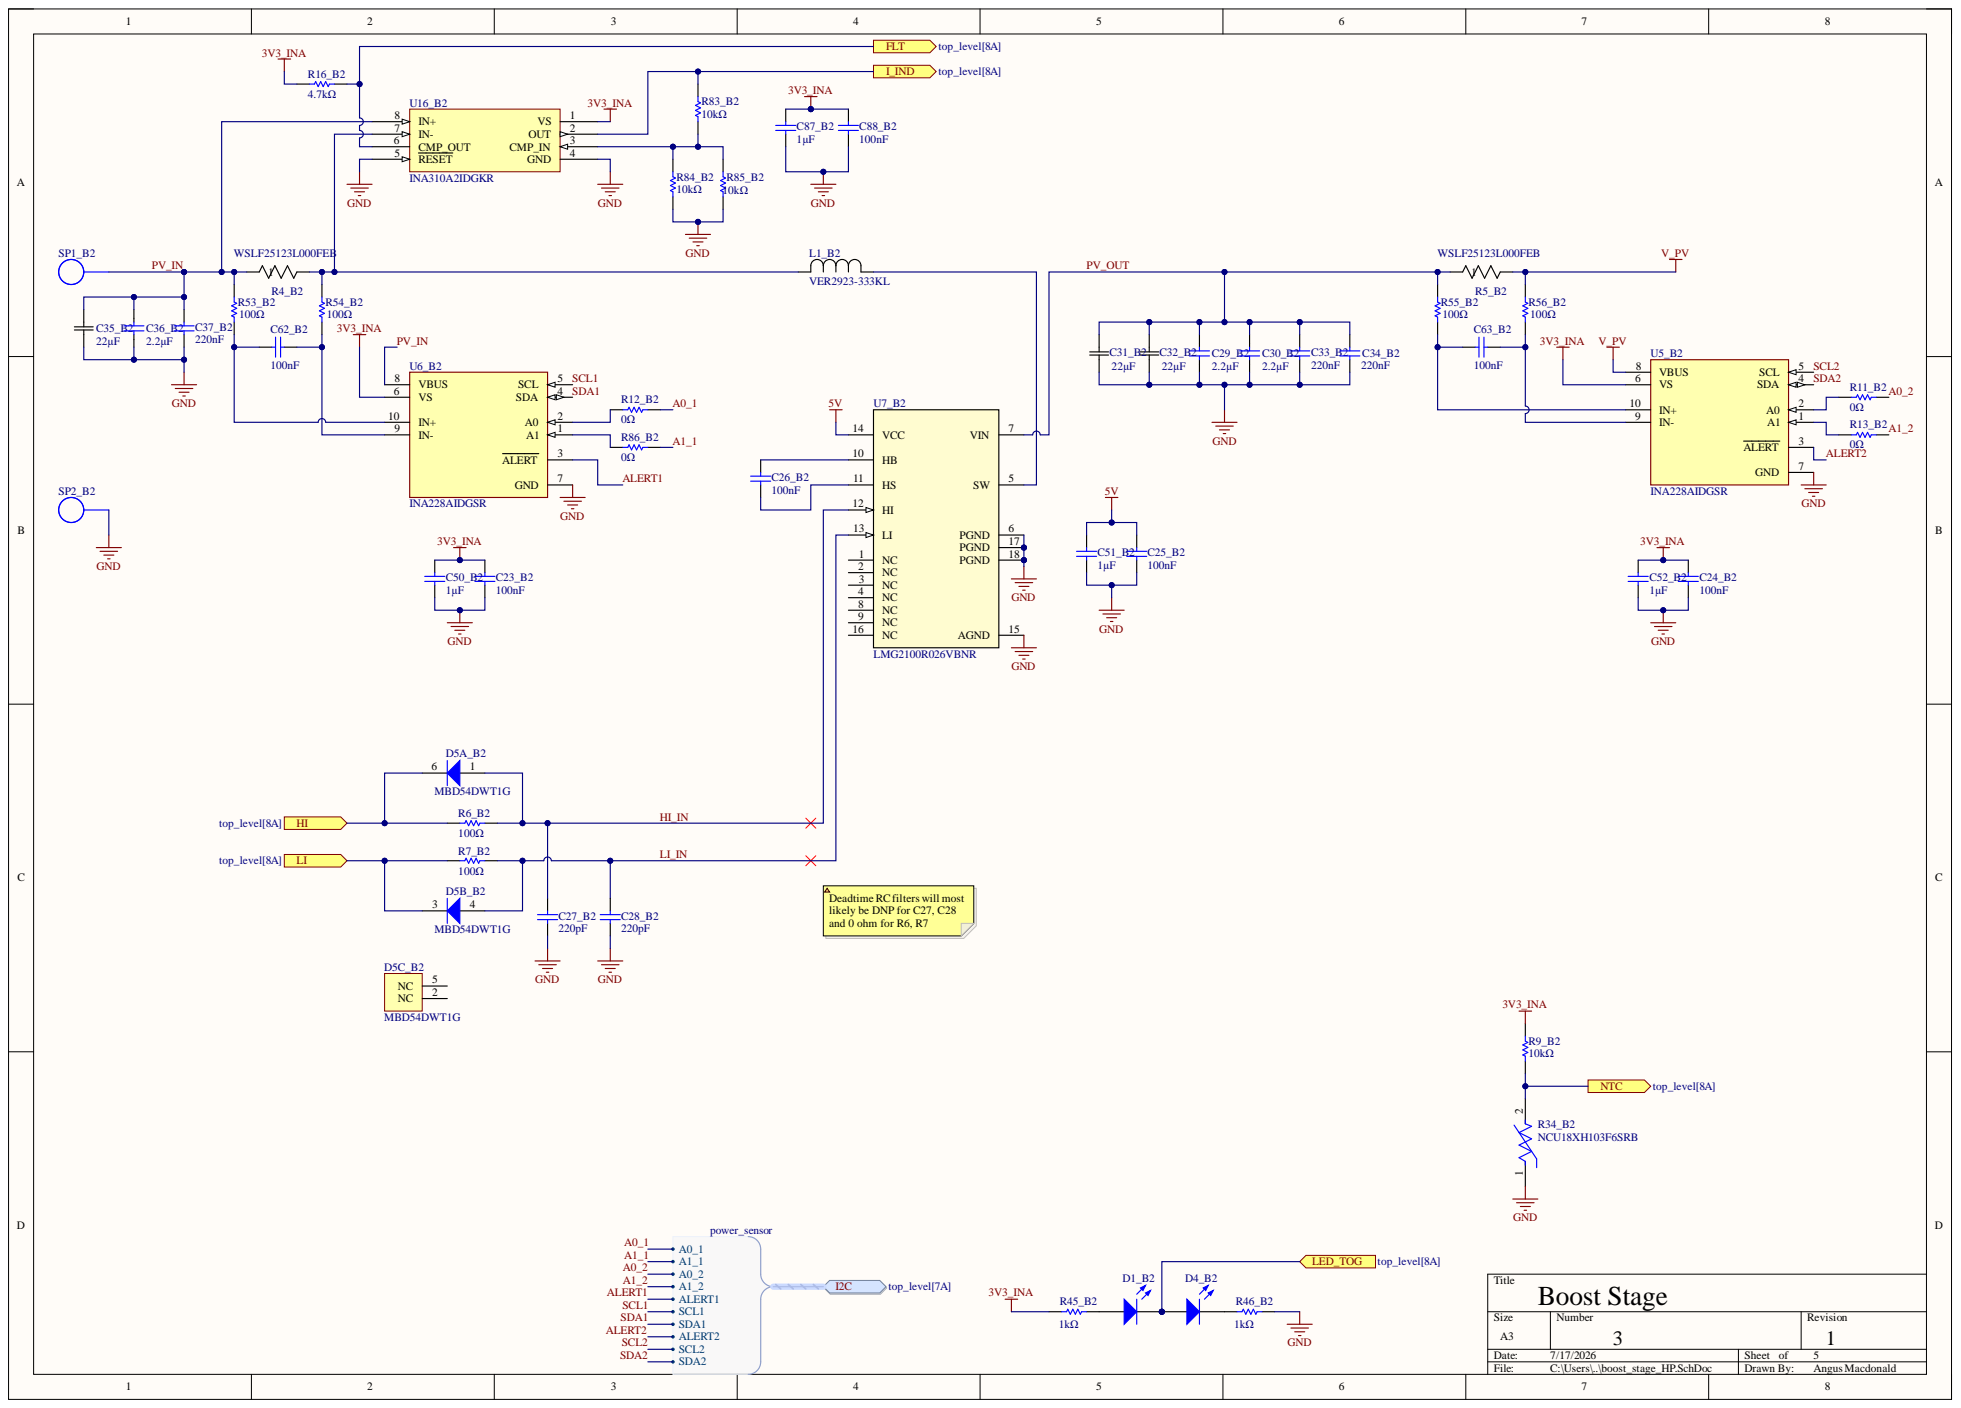
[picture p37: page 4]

Deadtime RCfilters will most
likely be DNP for C27, C28
and 0 ohm for R6, R7

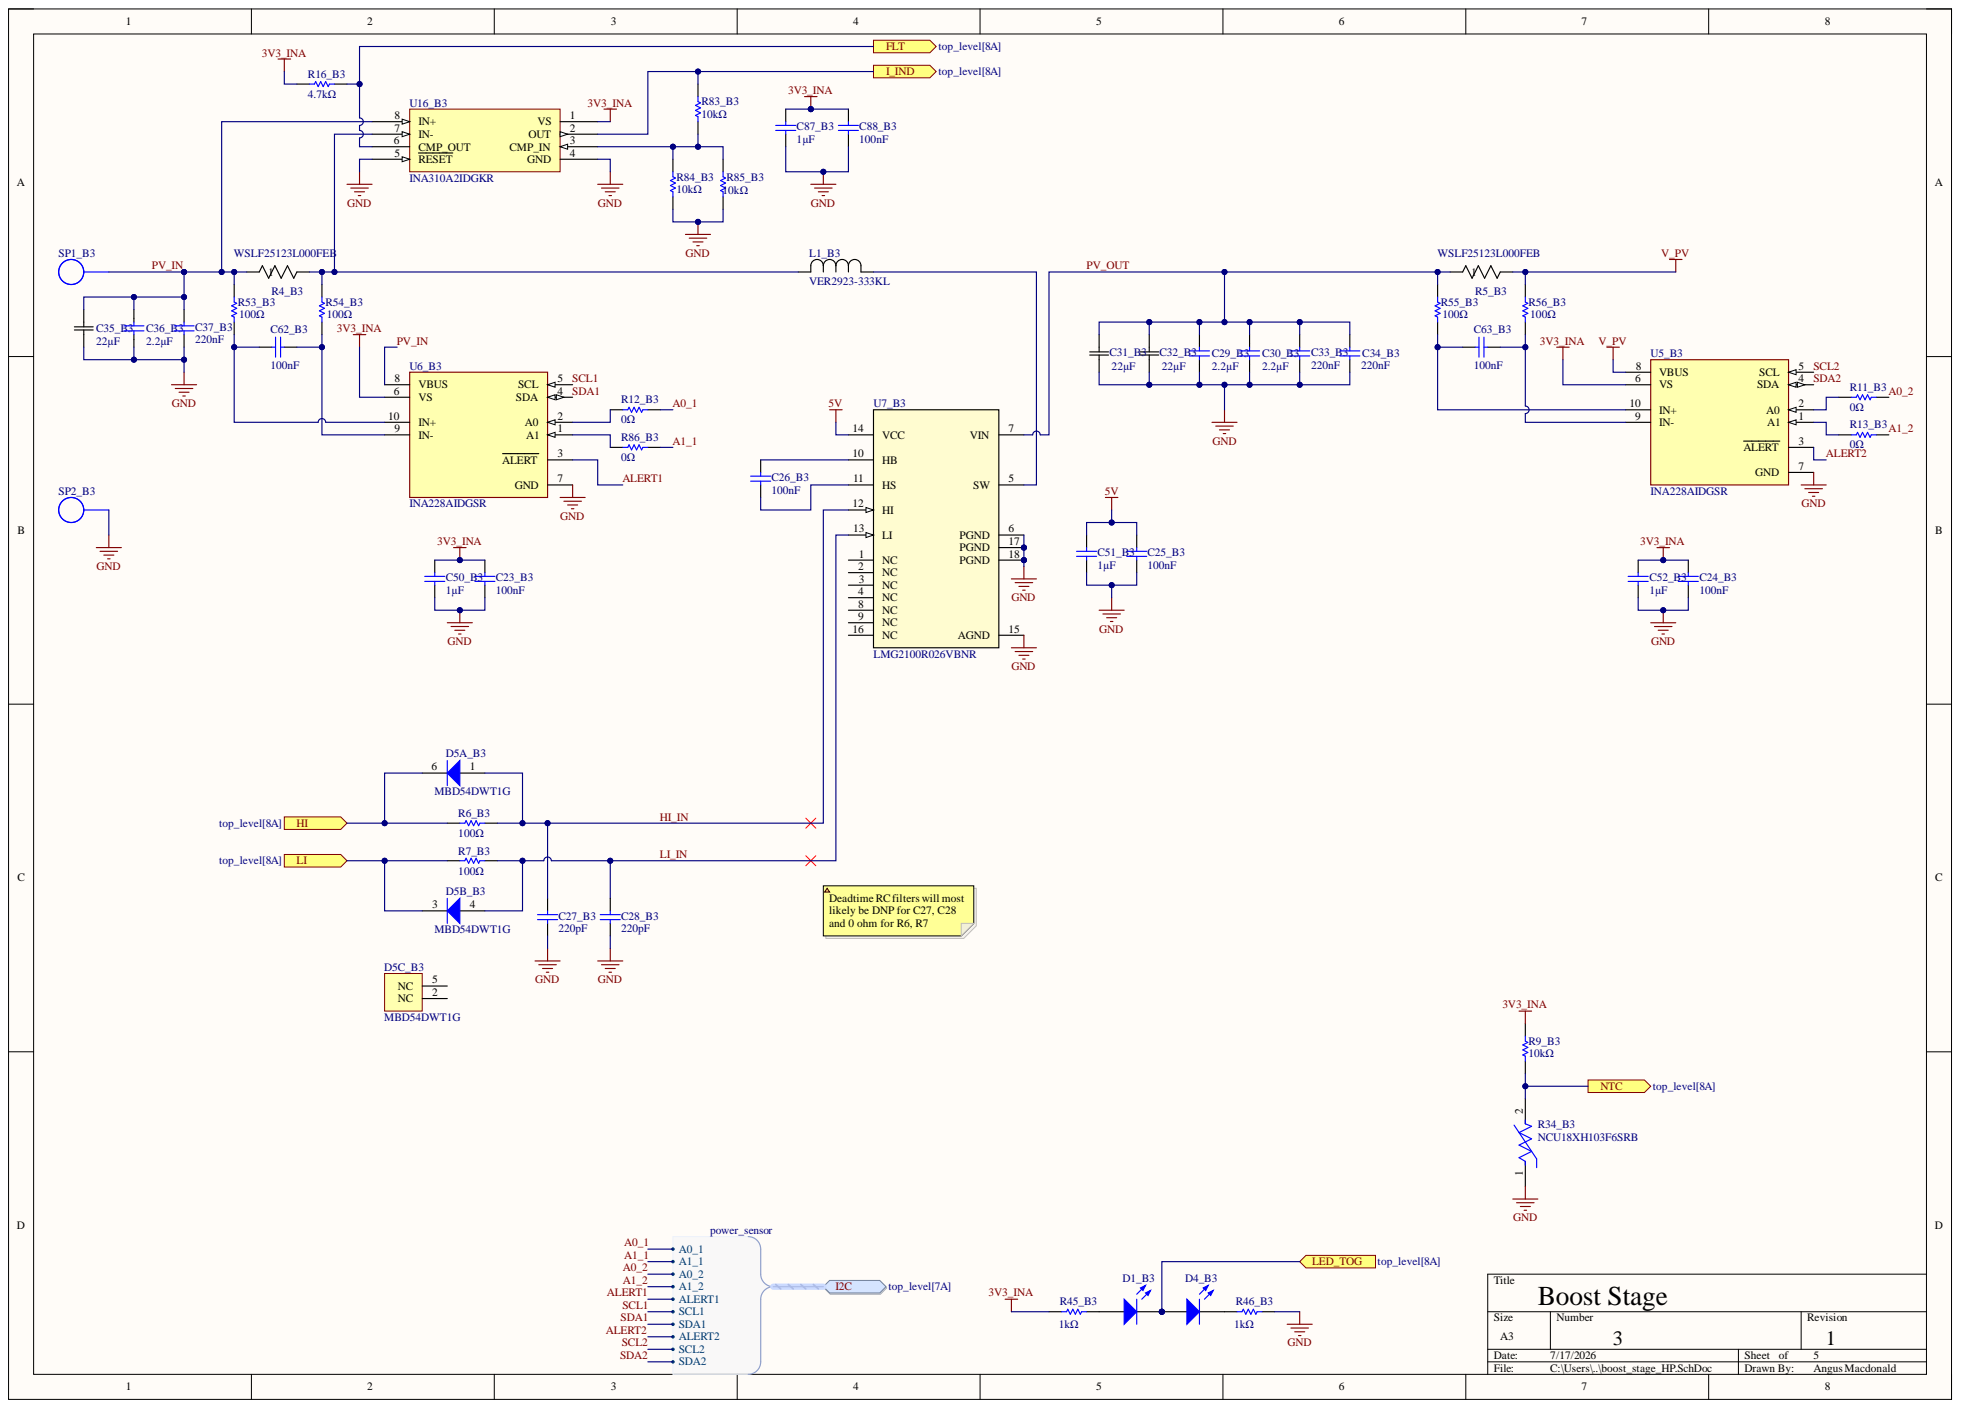
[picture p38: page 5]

Deadtime RCfilters will most
likely be DNP for C27, C28
and 0 ohm for R6, R7

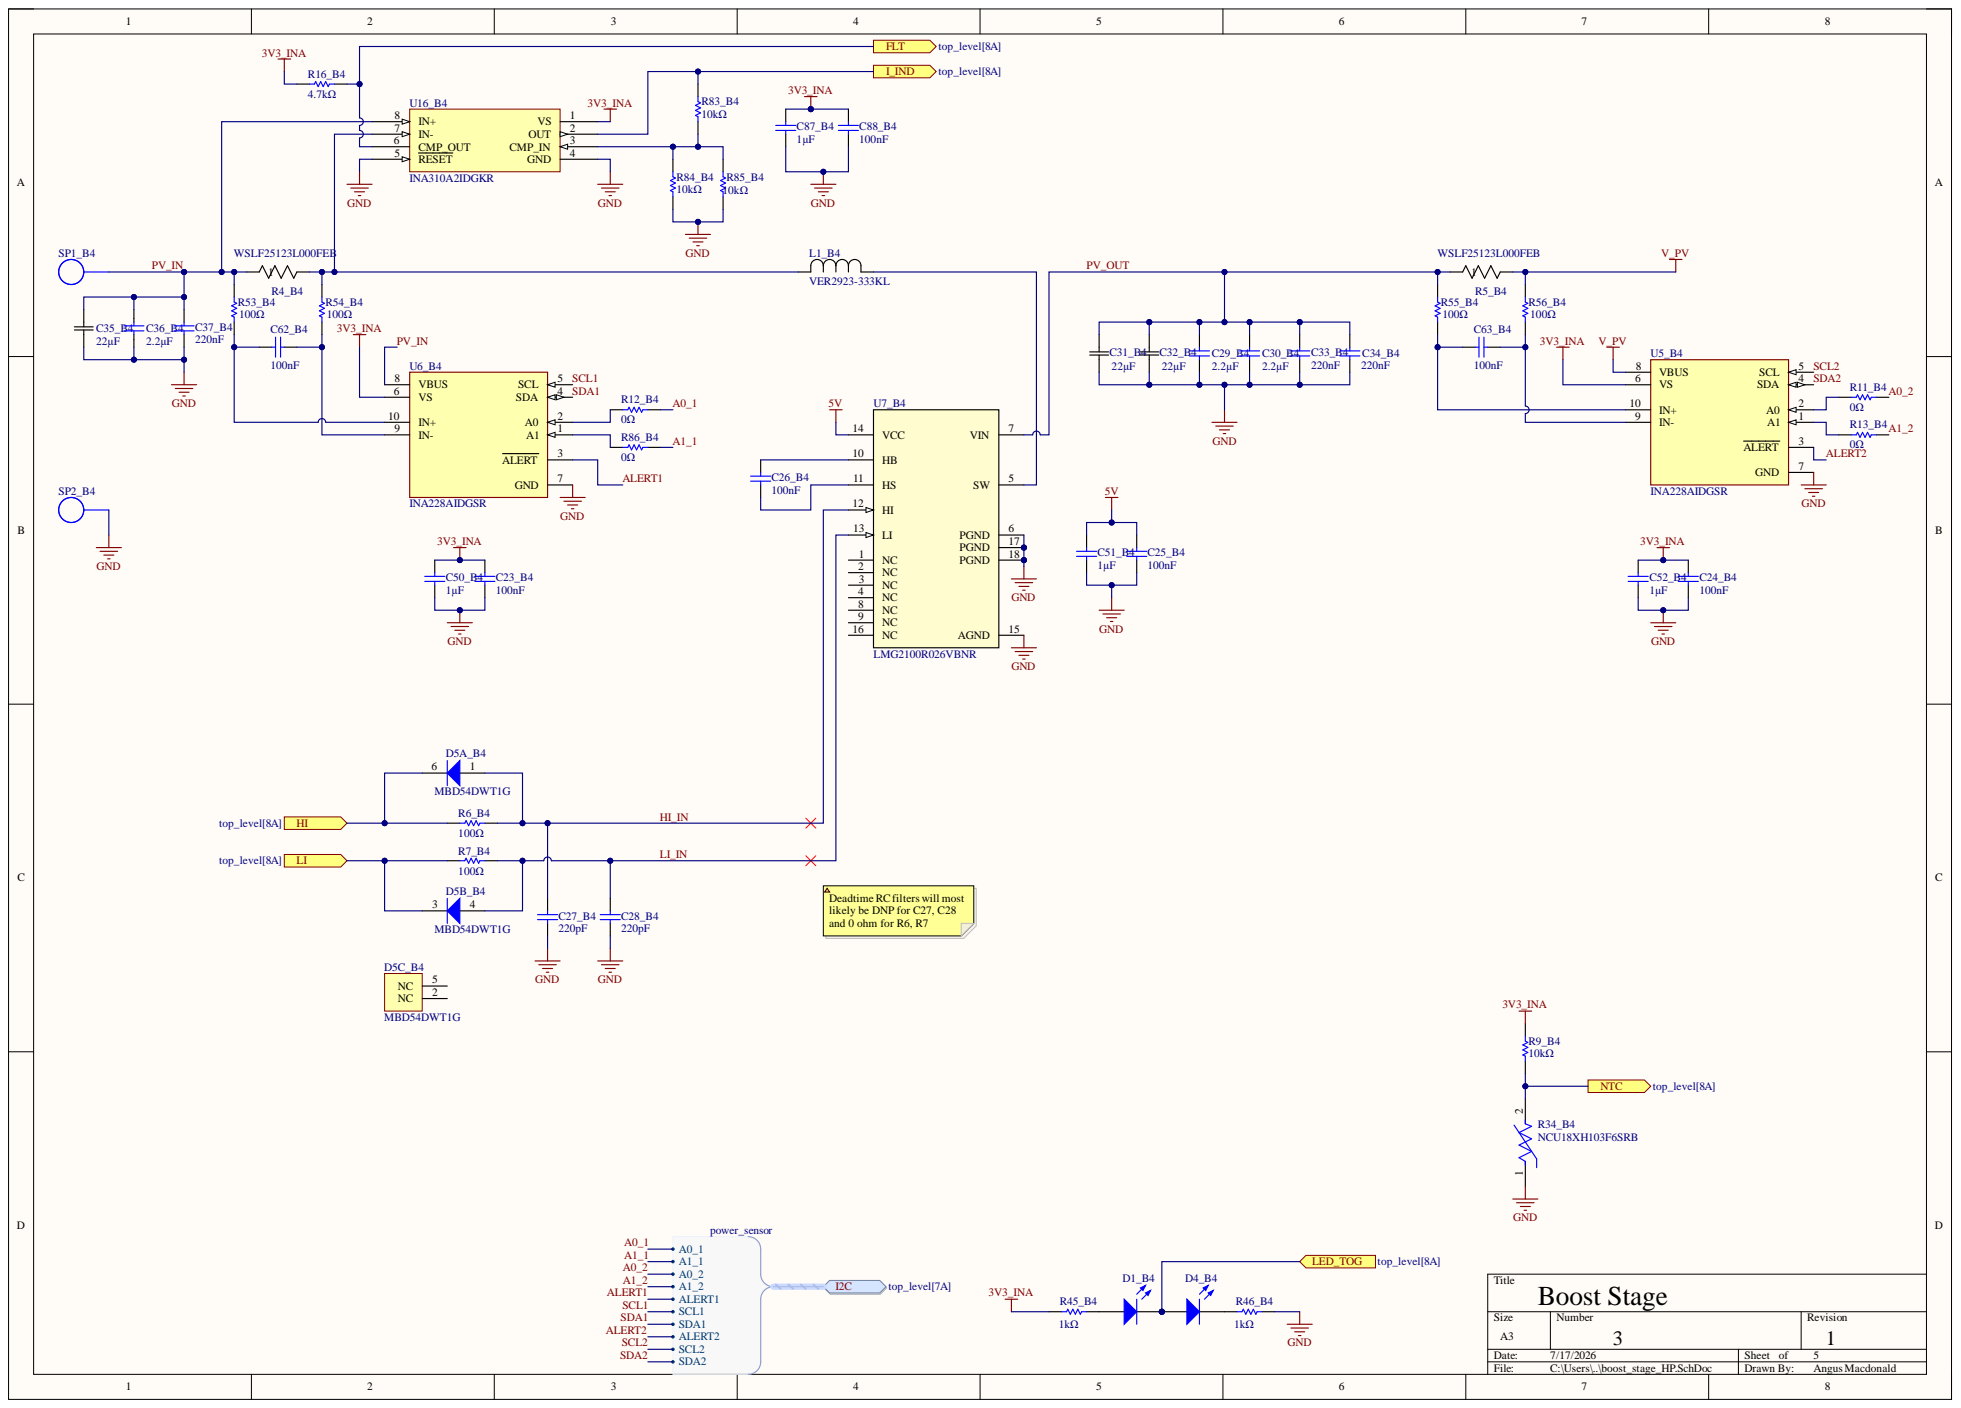
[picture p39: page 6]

Deadtime RCfilters will most
likely be DNP for C27, C28
and 0 ohm for R6, R7

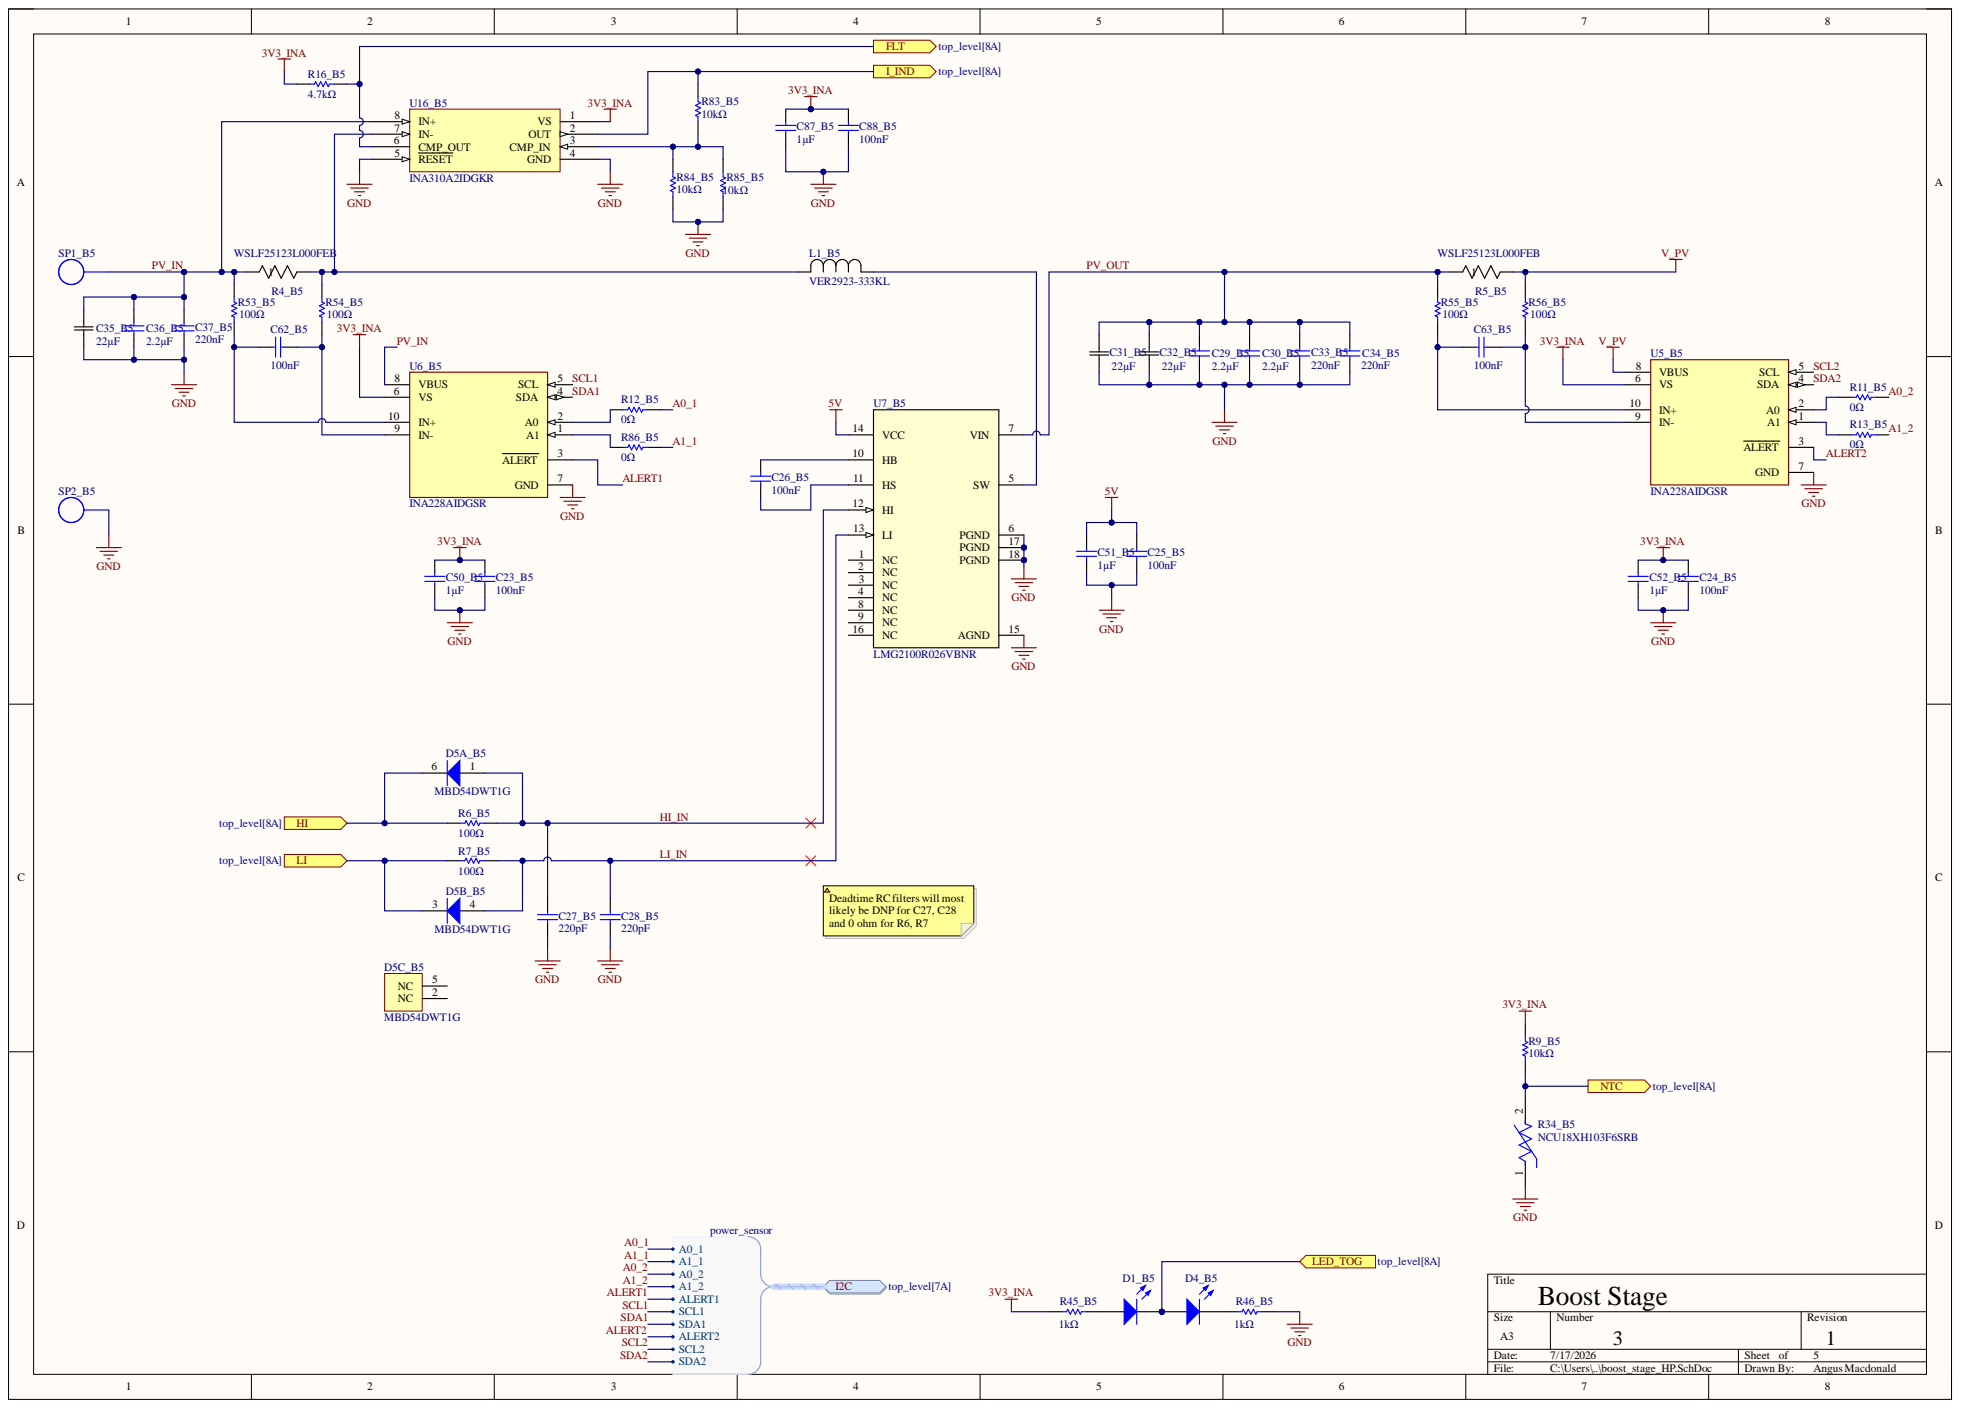
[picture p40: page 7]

Deadtime RCfilters will most
likely be DNP for C27, C28
and 0 ohm for R6, R7


Double check the values of
LMR51625 - Circuit from
Webench


GND 5
MNT 1 6







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

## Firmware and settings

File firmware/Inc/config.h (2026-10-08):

#ifndef CONFIG_H
#define CONFIG_H

#define CHANNEL_A     0U
#define CHANNEL_B     1U
#define CHANNEL_C     2U
#define CHANNEL_D     3U
#define CHANNEL_E     4U
#define CHANNEL_COUNT 5U

#define CHECK_TIMEOUT_MS 5000U

#define PWM_DEFAULT_FREQUENCY_HZ 300000U
#define PWM_DEFAULT_DUTY_CYCLE   0U
#define PWM_DEFAULT_DEAD_TIME_NS 20U

#define PWM_MIN_FREQUENCY_HZ 100000U
#define PWM_MAX_FREQUENCY_HZ 800000U
#define PWM_MIN_DUTY_CYCLE   0U
#define PWM_MAX_DUTY_CYCLE   850U
#define PWM_MIN_DEAD_TIME_NS 5U
#define PWM_MAX_DEAD_TIME_NS 300U

#define LED_BUS_ON_MV  35000U
#define LED_BUS_OFF_MV 34000U

#define TELEM_SWEEP_PERIOD_MS 40U
#define TELEM_STEP_TIMEOUT_MS 5U

#define ANALOG_PERIOD_MS 1U

#endif

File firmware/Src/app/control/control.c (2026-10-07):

#include "control.h"
#include "pwm.h"
#include "channel.h"
#include "main.h"

// Bench assumption: allow at most two 1 ms ramp intervals after a delayed pass.
#define RAMP_DT_MAX_MS 2U

static control_config_t *control_config;
static uint16_t requested_duty[CHANNEL_COUNT];
static const bool *channel_enabled[CHANNEL_COUNT];
static uint32_t last_duty_update_ms[CHANNEL_COUNT];

static void reset_requests(void) {
  const uint32_t now = HAL_GetTick();
  for (uint32_t i = 0; i < CHANNEL_COUNT; i++) {
    requested_duty[i] = 0;
    last_duty_update_ms[i] = now;
  }
}

static uint16_t calculate_starting_duty(channel_t *channel) {
  float vin = channel->telem.vin_v;
  float vout = channel->telem.vout_v;
  // Check if DC bus is energised.
  if (vout < 2.0f) {
    // Okay to start at zero, less then 2 volts probably indicates DC bus is not energized.
    return 0;
  }
  // Otherwise, use ideal duty cycle D = 1 - Vin/vout.
  float duty = 1.0f - (vin / vout);
  if (duty < 0.0f) duty = 0.0f;
  if (duty > 1.0f) duty = 1.0f;
  return (uint16_t)(duty * PWM_DUTY_SCALE);
}

void control_init(control_config_t *config) {
  control_config = config;
  reset_requests();
  if (!config) return;
  channel_enabled[CHANNEL_A] = &config->channel_a_enabled;
  channel_enabled[CHANNEL_B] = &config->channel_b_enabled;
  channel_enabled[CHANNEL_C] = &config->channel_c_enabled;
  channel_enabled[CHANNEL_D] = &config->channel_d_enabled;
  channel_enabled[CHANNEL_E] = &config->channel_e_enabled;
}

void control_start(uint32_t channel) {
  if (!control_config || channel >= CHANNEL_COUNT || !*channel_enabled[channel]) return;
  requested_duty[channel] = calculate_starting_duty(channel_by_id(channel));
  if (!pwm_start(channel, requested_duty[channel])) {
    control_stop(channel);
  }
  last_duty_update_ms[channel] = HAL_GetTick();
}

static uint16_t apply_ramp_rate(uint16_t requested, uint16_t applied, uint32_t dt_ms) {
  const uint64_t step = (uint64_t)control_config->ramp_rate_per_ms * dt_ms;

  if (requested > applied) {
    const uint32_t distance = requested - applied;
    if (step < distance) return (uint16_t)(applied + step);
  } else {
    const uint32_t distance = applied - requested;
    if (step < distance) return (uint16_t)(applied - step);
  }
  return requested;
}

static void update_duty(channel_t *channel, uint16_t requested, uint32_t dt_ms) {
  if (channel->pwm.op_state != PWM_STATE_RUNNING) return;
  if (control_config->ramp_limit_enabled) {
    requested = apply_ramp_rate(requested, channel->pwm.duty_applied, dt_ms);
  }
  (void)pwm_set_duty_cycle(channel->id, requested);
}

void control_service(uint32_t channel) {
  if (!control_config || channel >= CHANNEL_COUNT || !*channel_enabled[channel]) return;

  const uint32_t now = HAL_GetTick();
  uint32_t dt_ms = now - last_duty_update_ms[channel];
  last_duty_update_ms[channel] = now;
  if (dt_ms > RAMP_DT_MAX_MS) dt_ms = RAMP_DT_MAX_MS;

  update_duty(channel_by_id(channel), requested_duty[channel], dt_ms);
}

void control_set_duty(uint32_t channel, uint16_t duty_cycle) {
  if (!control_config || channel >= CHANNEL_COUNT || duty_cycle > PWM_MAX_DUTY_CYCLE) return;
  if (*channel_enabled[channel]) requested_duty[channel] = duty_cycle;
}

void control_stop(uint32_t channel) {
  if (!control_config || channel >= CHANNEL_COUNT) return;
  requested_duty[channel] = 0;
  last_duty_update_ms[channel] = HAL_GetTick();
  pwm_stop(channel);
}

void control_stop_all(void) {
  if (!control_config) return;
  for (uint32_t i = 0; i < CHANNEL_COUNT; i++) {
    if (*channel_enabled[i]) control_stop(i);
  }
}
